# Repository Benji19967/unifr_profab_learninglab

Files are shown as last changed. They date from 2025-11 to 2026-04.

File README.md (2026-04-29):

# Prototyping and Fabrication in the Learning Lab <!-- omit in toc -->

Project for the course Prototyping and Fabrication in the Learning Lab at the University of Fribourg.

Official course repo: https://github.com/nembrinj/protofablab/tree/main

<p float="left" align="left">
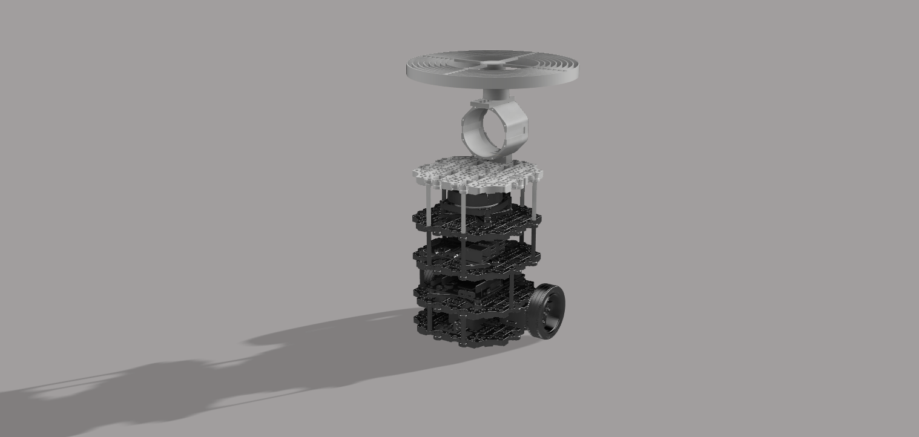
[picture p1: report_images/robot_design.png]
  
</p>

# Table of contents <!-- omit in toc -->
- [Abstract](#abstract)
- [Introduction](#introduction)
  - [Concept](#concept)
  - [Organisation](#organisation)
- [System Design](#system-design)
  - [System Architecture](#system-architecture)
  - [Robot Flow](#robot-flow)
  - [Interface](#interface)
- [Repository Structure](#repository-structure)
- [Hardware Designs](#hardware-designs)
  - [3D Printing](#3d-printing)
  - [Laser Cutting Machine](#laser-cutting-machine)
- [Process](#process)
- [Challenges](#challenges)
- [Future Work](#future-work)
- [Conclusions](#conclusions)

# Abstract

This project presents the design and implementation of a robotic scenographic system developed for a theatrical performance set on a train journey. Using a TurtleBot Burger, programmable lighting, and digitally fabricated components, the system projects dynamic shadows to simulate the perception of movement on stage. The project combines autonomous robot navigation, interactive control interfaces, and custom mechanical structures created through 3D printing and laser cutting. The result is a flexible and controllable scenic element that enhances the visual narrative of the performance through light and motion.

# Introduction

The objective of the project was to contribute to a stage performance through a technological element that enhances the visual narrative without interfering with the physical constraints of the play.

The theatrical piece is set during a train journey and is performed by a single actress who remains physically fixed to the stage, moving only from the ankles upwards. This limitation motivated the search for an alternative way to convey motion and spatial progression. To address this challenge, a TurtleBot Burger was adapted and extended with custom hardware to generate dynamic light and shadow effects on stage, simulating the changing landscape seen from a train window.

The project combines autonomous robot navigation, interactive control systems, and custom-designed mechanical components produced using 3D printing and laser cutting. Together, these elements form a flexible scenographic system capable of adapting to different moments of the performance and reinforcing the theatrical atmosphere through light, motion, and shadows.

## Concept

The core concept of the project is the use of moving shadows to suggest the sensation of travel and continuous motion within a static stage environment. By projecting silhouettes of external elements such as buildings, trees, or light poles, the system recreates the visual experience of observing the outside world through a train window.

This effect is achieved by mounting a programmable light source and a rotating structure with interchangeable silhouettes on top of a mobile robot. As the circular structure rotates, the projected shadows move across the stage, creating the illusion of a passing landscape. The distance between the light source and the silhouettes can be modified, allowing different shadow scales and visual depths.

This approach was particularly well suited to the play, as it adds dynamism to the scene without requiring additional actors or complex stage mechanisms. The robotic system remains in the background while its visual impact supports the narrative, reinforcing the idea of movement and transition that is central to the story.

## Organisation

The project was carried out by a team of two students. Due to living far from each other, in-person meetings outside scheduled class time were limited. As a result, a structured and continuous communication workflow was established.

Each week, during the class session, both team members shared and discussed the progress made individually throughout the previous week. After reviewing the current state of the project, development continued collaboratively during the class. At the end of each session, specific tasks were assigned to be completed before the following week.

In addition, any complications, technical issues, or new ideas that arose during the week were communicated via phone. When physical presence was required, such as for hardware assembly or testing, meetings were arranged before class sessions to work together on-site. This organization allowed the project to progress efficiently despite the physical distance between team members.

# System Design

Communication between electronic parts was handled wirelessly using the Robot Operating System (ROS).

The light has an integrated Arduino. The stepper motor was connected through a driver to another Arduino. Both Arduinos could be configured to connect to WiFi. On both of them a ROS package was installed, which allowed serialized communication with ROS Core running on a laptop. The light is configurable in two ways: the intensity can be adjusted, and it can be made to blink at different frequencies. For the motor, the speed and direction of rotation is configurable. 

Sending commands to the light and motor can be done via ROS commands through the CLI, or via Python code, or via a Node-RED interface. The team members ended up using the Node-RED interface as it is most flexible and easy to set up. The auto-generated Node-RED config for the final interface can be found [here](node-red/interface.json).

The code for the light Arduino can be found [here](arduino/light_ros/light_ros.ino) and the code for the motor Arduino [here](arduino/motor_ros/motor_ros.ino).

An attempt was made to make the robot fully autonomous via Python code. The code is not fully tested / functional, but can be found [here](src/turtlebot3_profab/scripts/controller.py). The launch script for the controller can be found [here](src/turtlebot3_profab/launch/controller.launch).

Mapping the environment and localizing the robot still need to be done manually. Instructions for how to do so and for many other commands can be found in the [docs](docs/instructions.md). The [makefile](makefile) provides shortcuts for many commonly used commands. 

## System Architecture

The intelligence and control center of the robot is located on the laptop. There are several ROS nodes running on the laptop:

- ROS core — in charge of coordination between all the nodes. 
- ROS serial nodes - to allow serial communication between the Arduinos and the ROS language.
- ROS server - is a bridge to allow communication between ROS core and Node-RED
- ROS navigation - in charge of coordinating robot navigation and going to goal poses using a predefined map. 

During the mapping and localization phase of the robot the following other nodes are also used:

- ROS slam - to use the lidar and create a map of the environment
- ROS teleop - to allow remote control of the robot using keyboard keys
- ROS gazebo - to run the robot in a simulation environment

The robot has a core ROS node that enables its basic functionalty and optionally a controller that allows it to navigate autonomously. 

There are ROS topics for goal navigation, motor speed control, as well as light intensity and blinking control. 

<p align="center">
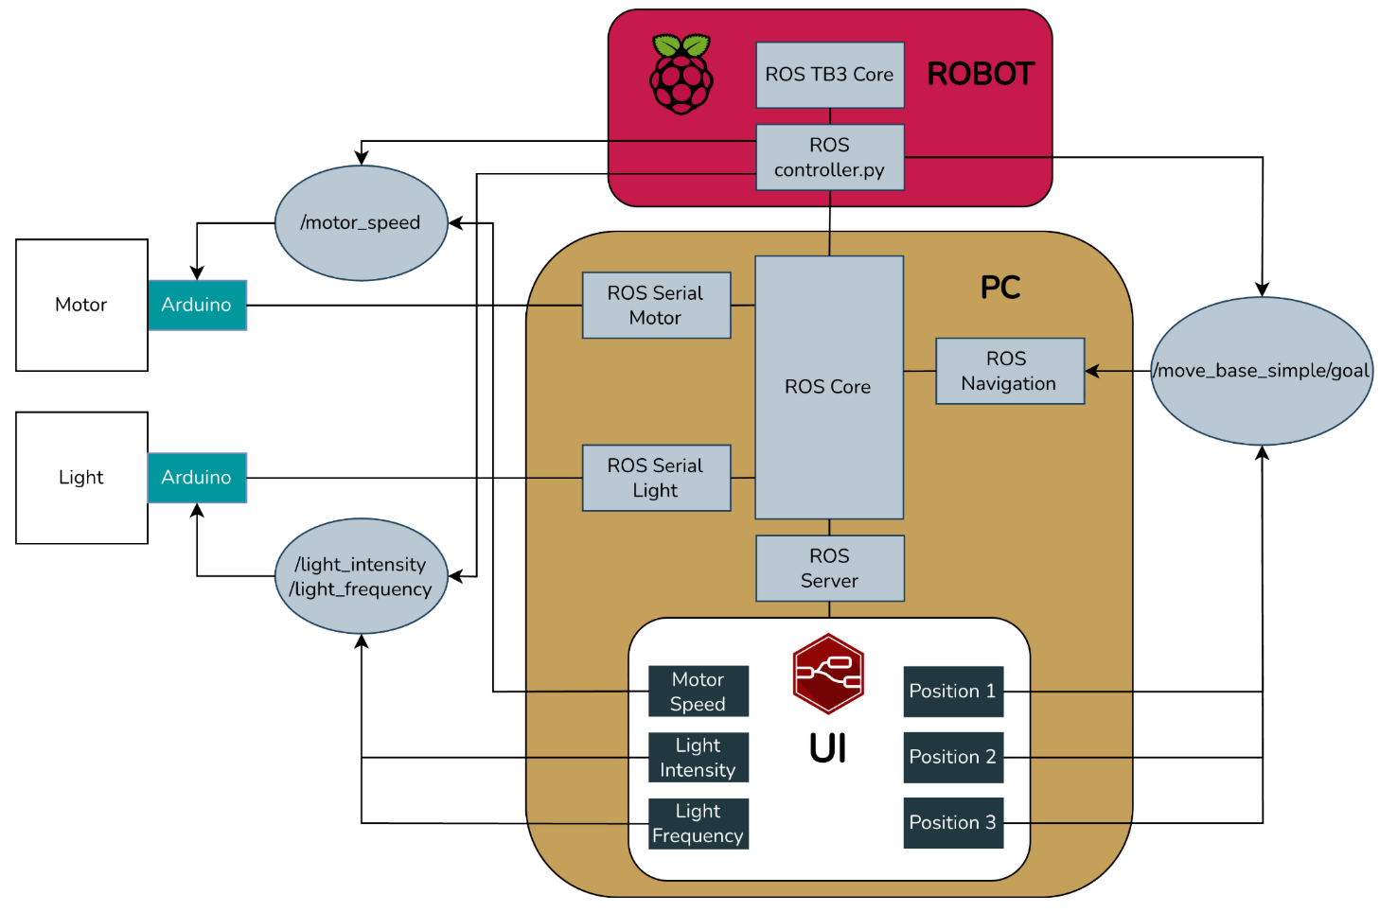
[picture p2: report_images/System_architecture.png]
System Architecture schema
  
</p>

## Robot Flow

The flow of the robot for the project is as follows. First the environment is mapped and saved manually. Then, using the RVIZ interface the coordinates of three goal poses are obtained, which are inserted into the Node-RED UI. Then the robot is launched and one of the goal poses is chosen in the UI. In response, the robot will move to the defined pose. Once there, the light and motor are manually turned on which starts the projection of the shadow scene onto the background. The light intensity, blinking frequency, and motor rotation speed can all be adjusted. Once the play is over, the robot goes back behind the scene.

<p align="center">
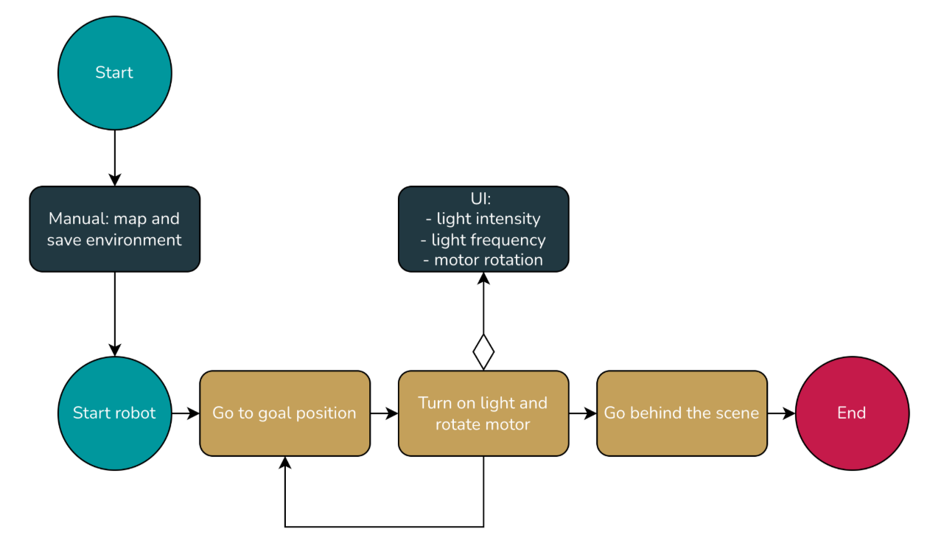
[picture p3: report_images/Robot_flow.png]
Robot flow schema
  
</p>

## Interface

Light, motor and robot position control all happen through a Node-RED interface that talks to the respective components via ROS topics. The three positions define goal poses and, when clicked, send the robot in front of one of the scenes to project the shadow. 

<p align="center">
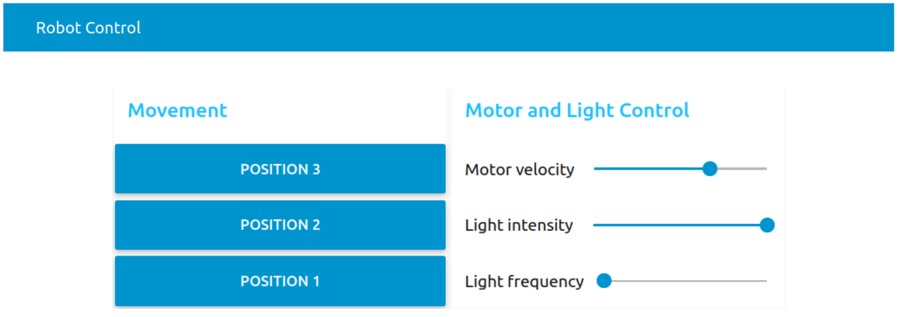
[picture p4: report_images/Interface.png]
Interface
  
</p>

# Repository Structure

    .
    │
    ├── 3d_models                           # 3D models of pieces to print —- .mf and .bgcode files
    │
    ├── arduino                             # Arduino code to control the light and motor
    │
    ├── docs                    
    │   ├── hardware.md                     # Hardware used for the project
    │   └── instructions.md                 # How-tos: Raspberry Pi, Arduinos, Node-RED, Turtlebot, ROS
    │
    ├── map                                 # Maps of the environment created using ROS Navigation
    │   
    ├── node-red                            # Node-RED dashboard files
    │   
    ├── report_images                       # Assets used in the report
    │   
    ├── requirements                        # Dependencies needed to set up the robot and the workstation
    │
    ├── src / turtlebot3_profab / launch    # Launch scripts
    │
    ├── src / turtlebot3_profab / scripts   # Python scripts to control the robot
    │
    ├── makefile                            # Shortcuts for ROS commands 
    │
    └── README.md

# Hardware Designs

Several custom components were required to support the lighting system, the rotating shadow mechanism, and the additional electronics while maintaining stability and modularity.
Digital fabrication tools played a key role in this process. 3D printing was used to create structural and mechanical supports, while the laser cutting machine was employed to produce the shadow silhouettes and flat components. These techniques allowed for rapid iteration, precise customization, and easy adaptation of the system to the requirements of the performance.

## 3D Printing

3D printing was used to fabricate all custom structural components required to extend the TurtleBot Burger and integrate the lighting and shadow projection system. These parts were designed to be modular, lightweight, and easy to assemble, allowing the system to be mounted securely on top of the robot without interfering with its original structure or sensors.

The printed components include an additional base, support structures for the programmable light, and a vertical mount to hold the stepper motor responsible for rotating the shadow element. The light support was designed with multiple mounting positions on the base, enabling adjustments to its height and placement. Similarly, the motor could be mounted in different positions on the light support, providing flexibility in the overall configuration.
The rotating piece placed above the motor was also designed with several concentric positions to attach silhouette elements. This modular arrangement makes it possible to vary the distance between the light source and the silhouettes, which is a key aspect of the system. Adjusting this distance significantly affects the resulting shadows, influencing their size, sharpness, and overall visual appearance. This flexibility allows the system to adapt to different silhouettes and stage scenarios, producing distinct visual effects depending on the desired atmosphere.

In the image of the left, the custom 3D-printed components can be seen assembled on the TurtleBot Burger. The printed parts are shown in white, clearly distinguishable from the original robot components, which are black. This contrast highlights the added structures and their integration with the existing platform.

The right image shows only the 3D-printed parts prior to assembly. This view emphasizes the modular nature of the design and the variety of supports created to accommodate the different hardware elements. The use of 3D printing allowed rapid prototyping and iterative refinement of these components throughout the development process.

<p float="left" align="center">
  
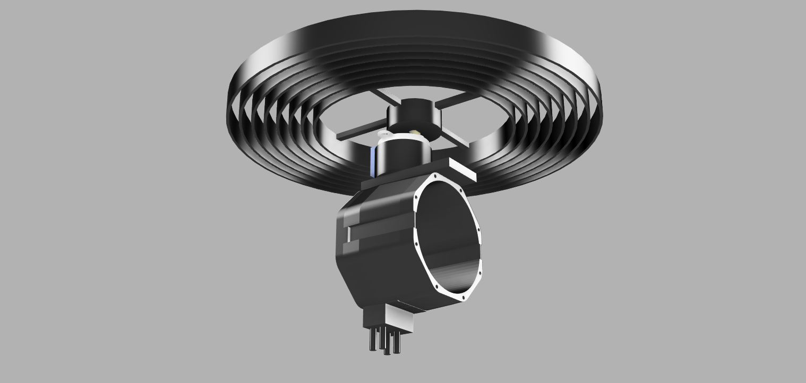
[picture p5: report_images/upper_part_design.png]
  
</p>

## Laser Cutting Machine

The laser cutting machine was used to fabricate the silhouette elements responsible for generating the projected shadows. For this purpose, it was necessary to select a material that was lightweight and easy to cut, while also being more resistant and stable than standard paper. A paper with higher grammage than a regular sheet was chosen, as it provided the required balance between rigidity, durability, and low weight.

The silhouettes were designed digitally and then cut using the laser cutting machine. This approach was significantly more efficient and less costly in terms of time and effort than manual cutting. Once the designs were prepared, the fabrication process was straightforward and easily repeatable.

One of the main reasons for using laser cutting was the high level of precision and the clean edges it provides. This aspect was especially important for the project, as small imperfections in the silhouettes become highly noticeable when projected as shadows. Clean and accurate cuts resulted in sharper, more defined shadows, directly improving the visual quality of the final scenographic effect.

<p align="center">
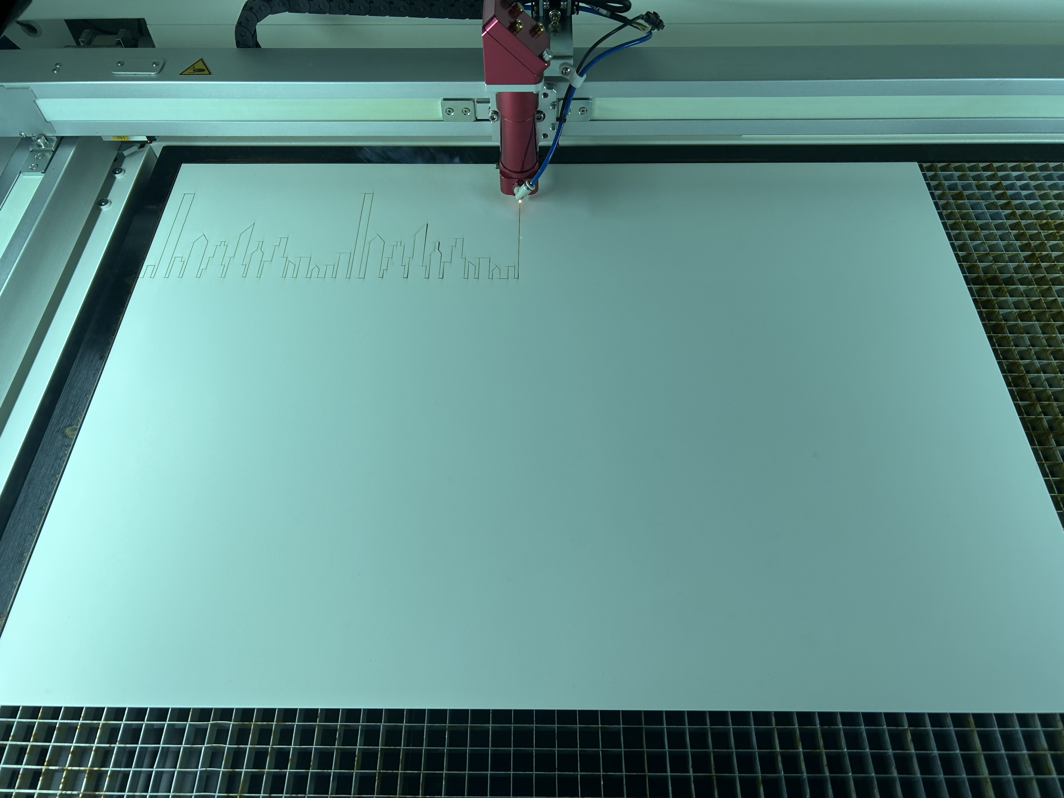
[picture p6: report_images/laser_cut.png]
Laser cut
  
</p>

# Process

The development of the project followed an iterative process that combined research, hardware fabrication, and software implementation.

The first step consisted of evaluating the feasibility of the initial idea. This phase focused mainly on researching the type of motor required for the rotating shadow mechanism. It was determined that a stepper motor was more suitable than a servo motor due to the need for continuous and controllable rotation. In parallel, different lighting solutions were explored in order to generate clear and defined shadows. This issue was later solved when suitable programmable lights were provided. Additionally, initial tests with 3D printing were carried out, revealing that printing components was time-consuming and required careful planning to avoid delays.

After this initial research phase, a basic planning stage was carried out to ensure that all project deadlines could be met while accounting for possible setbacks. The fabrication of 3D-printed components was prioritized, as multiple iterations were expected due to potential design errors or failed prints. Furthermore, several of these components were essential to begin testing the robot in real conditions.

The first parts to be designed and printed were the additional base for the robot and the initial support structures. While these components were being printed, work began on the implementation of the robot’s navigation and mapping system, allowing progress on both hardware and software in parallel.

At a later stage, once the stepper motor and the lighting system were available, the design and printing of the light support, the motor mount, and the rotating piece for holding the silhouettes were carried out. During this period, the control code for the stepper motor and the programmable light was developed and tested independently.

<p align="center">
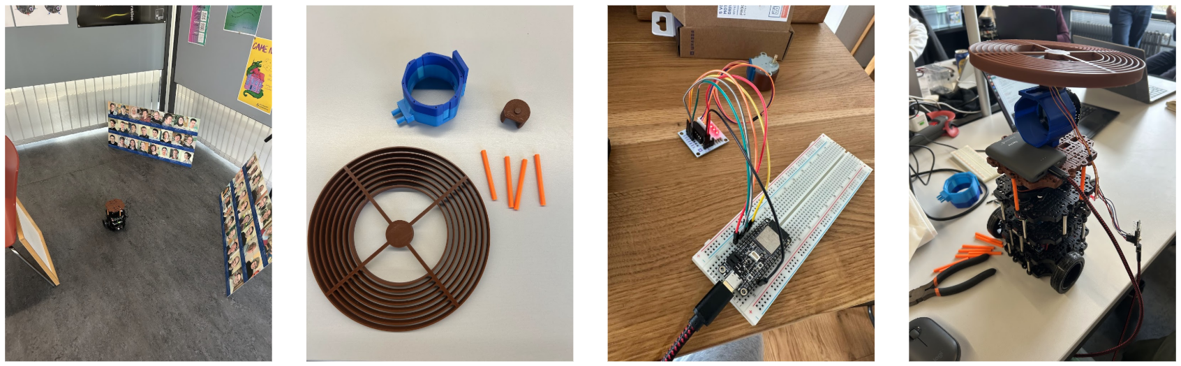
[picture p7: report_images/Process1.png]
First images of the process
  
</p>

With these components printed and assembled, the system was tested as a whole, which led to the identification of several issues. The main problem was that the initial rotating piece was too small, causing the silhouettes to be positioned too close to the light source and resulting in poor shadow quality. To address this issue, a new and larger rotating piece was designed and printed. At the same time, development of the user interface continued, and the overall software was automated to allow the entire system to be executed easily, enabling any user to control the robot through the interface without technical knowledge.

<p align="center">
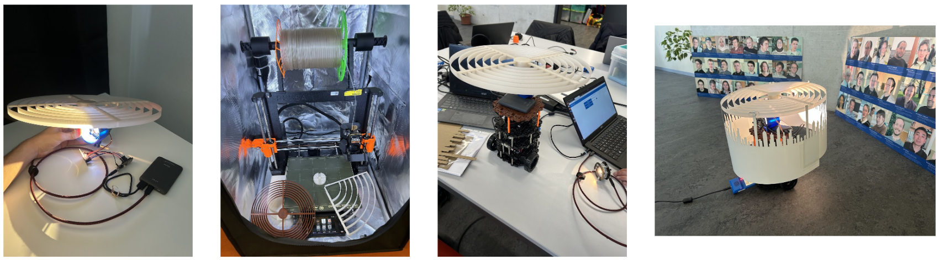
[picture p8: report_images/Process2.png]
Last images of the process
  
</p>

Finally, once all components were correctly fabricated, assembled, and integrated, the last phase focused on fine-tuning the system. Multiple simulations and tests were performed to determine the most effective configurations for rotation speed, light intensity, and distance between the light source and the silhouettes, ensuring the best visual results for the stage performance.

<p align="center">
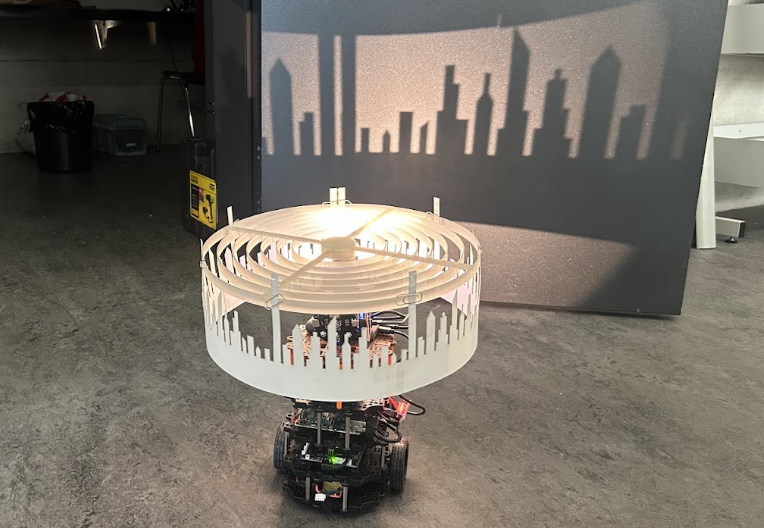
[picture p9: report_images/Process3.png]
Final version
  
</p>

# Challenges

One of the first challenges was the selection of the appropriate motor for the rotating shadow mechanism. The system required a motor capable of rotating continuously in both directions without limitation. A servo motor was not suitable for this purpose, as it can only rotate within a fixed angular range. After researching different options, a stepper motor was selected, as it allows precise and unlimited rotation control. However, finding a stepper motor compatible with Arduino and with low power requirements introduced additional constraints. To meet these requirements, the use of a motor driver was necessary, adding complexity to both the hardware setup and the software control.

Another major challenge was achieving the correct alignment between the light source and the silhouettes to obtain high-quality shadow projections. Depending on the type of silhouettes used and the specific stage configuration, the required distances and sizes varied significantly. Finding an optimal configuration through trial and error would have been inefficient and costly. To address this, several adjustable components were incorporated into the robot design. The light support could be mounted in different positions on the base, allowing the light to be placed either at the center or offset from it. The motor could also be positioned at varying distances relative to the light source, depending on whether the rotating element needed to align centrally or not. Finally, the rotating piece itself featured multiple concentric positions for attaching silhouettes, enabling fine control over the distance between the light and the silhouettes. Although this approach increased the complexity of the mechanical design, it significantly reduced printing time and material waste while providing great flexibility and precise shadow control.

The fabrication of the rotating piece presented an additional challenge. The initial design was too small, resulting in silhouettes being placed too close to the light source and producing poor shadow quality. When redesigning the piece at a larger scale, the 3D printer was unable to print it as a single component due to size limitations. To overcome this, the rotating piece was redesigned as a modular structure composed of six interlocking parts. This solution ensured sufficient size while maintaining structural robustness and low weight. Careful attention was given to weight distribution, as uneven mass or imprecise assembly could cause imbalance during rotation, negatively affecting the shadow effect. The modular design allowed precise assembly without excessive use of adhesive, minimizing the risk of imbalance.

Finally, several challenges were encountered during software execution and system integration. At times, the robot failed to connect correctly, localization was inaccurate, or the motor and light systems stopped responding. Through iterative debugging, it became clear that the order in which different components and processes were executed was critical. Additionally, maintaining a consistent stage setup after the environment had been mapped proved essential, as any change affected localization accuracy. Ensuring stable power connections, particularly avoiding disconnections of the motor or light once integrated with the ROS system, was also identified as a key factor for reliable operation.

# Future Work

One potential improvement is the ability to project multiple static scenes without the need to change silhouettes manually and without relying on continuous motion. This could be achieved by designing a single rotating disc containing several static scenes distributed along its diameter. In this configuration, the robot would move to a specific position on the stage and project a selected scene. When a scene change is required, the rotating piece would rotate by a small, controlled angle to align a different scene with the light source. This approach would allow multiple scenes to be stored on the robot and displayed sequentially through minimal rotation.

Another possible extension is the creation of two concurrent scenes with a parallax effect. In this scenario, two different silhouette layers would rotate in opposite directions, generating a greater sense of depth and visual complexity. Achieving this effect would require the integration of an additional motor and a modification of the robot’s mechanical structure to allow both rotating elements to move independently while keeping the light source fixed. This enhancement could significantly enrich the visual language of the system and open new creative possibilities for stage design.

# Conclusions

This project demonstrates how robotics and digital fabrication can be effectively applied to a theatrical and scenographic context. By combining autonomous robot navigation, programmable lighting, and custom-fabricated mechanical components, it was possible to create a dynamic visual system that enhances the narrative of the performance without adding physical actors or complex stage machinery.

The use of shadows as a primary visual element proved to be a suitable solution for conveying movement in a constrained stage environment. The modular and adjustable design of the hardware allowed the system to adapt to different silhouettes, lighting conditions, and stage configurations, highlighting the importance of flexibility in prototyping for artistic applications.

Throughout the development process, the project emphasized iterative design, problem-solving, and the integration of hardware and software. Challenges related to motor selection, fabrication constraints, and system reliability provided valuable insights into the practical limitations and considerations of working with robotic platforms in real-world scenarios.

Overall, the project successfully met its objectives and illustrates the potential of repurposing robotic systems as expressive tools in performance and learning environments. The resulting system offers a solid foundation for future extensions and further exploration of robotics as a medium for artistic expression.

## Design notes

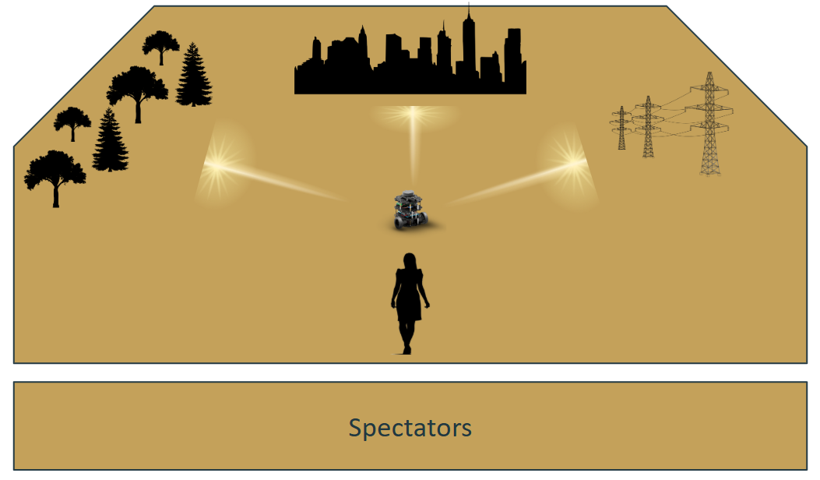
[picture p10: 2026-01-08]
report_images/Stage.png

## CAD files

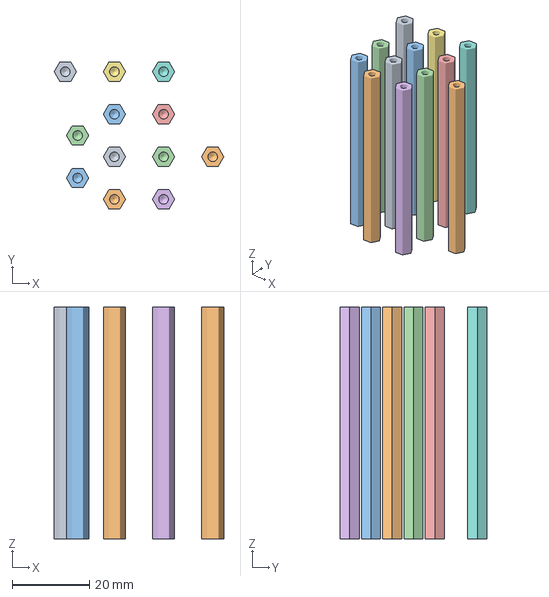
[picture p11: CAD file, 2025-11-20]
3d_models/SUPPORT_HEX_M3_0XL60_FF_multiple.3mf
43.9 x 38.0 x 60.0 mm

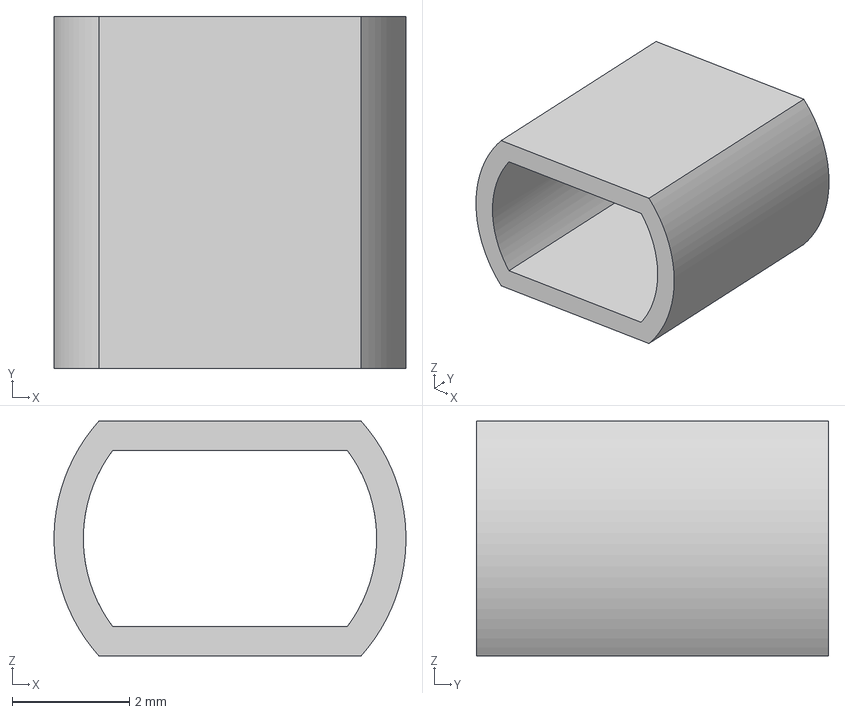
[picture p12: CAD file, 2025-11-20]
3d_models/motor_adapter_1.3mf
6.00 x 6.00 x 4.00 mm

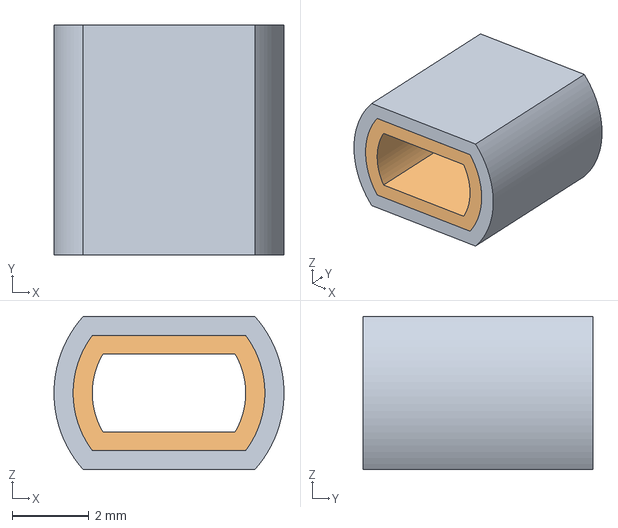
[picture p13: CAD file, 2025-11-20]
3d_models/motor_adapter_2.3mf
6.00 x 6.00 x 4.00 mm

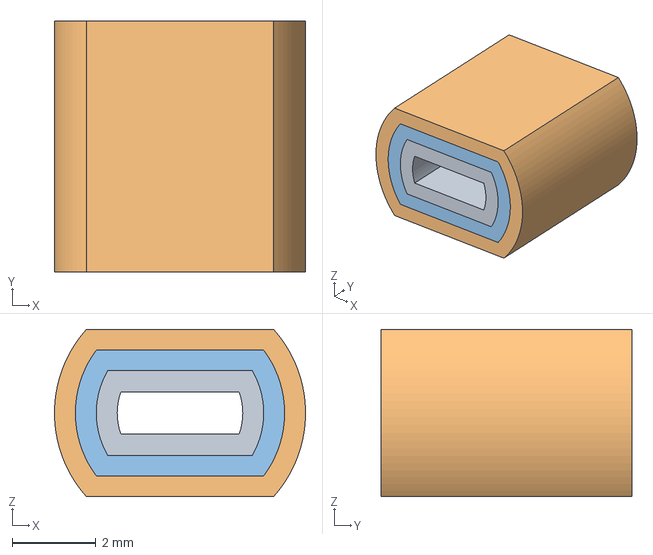
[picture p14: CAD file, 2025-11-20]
3d_models/motor_adapter_3.3mf
6.00 x 6.00 x 4.00 mm

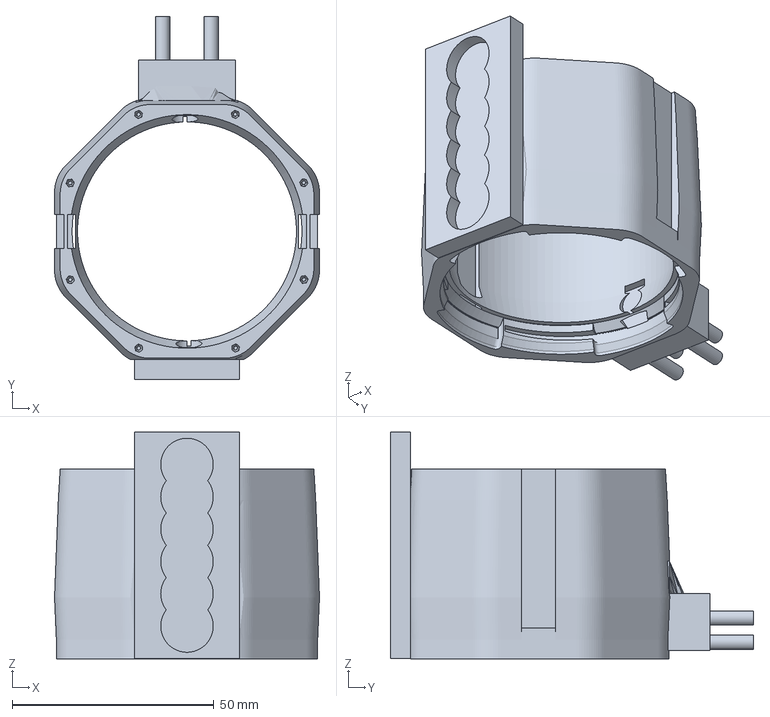
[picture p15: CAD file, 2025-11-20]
3d_models/light_tube.3mf
65.6 x 90.0 x 56.1 mm

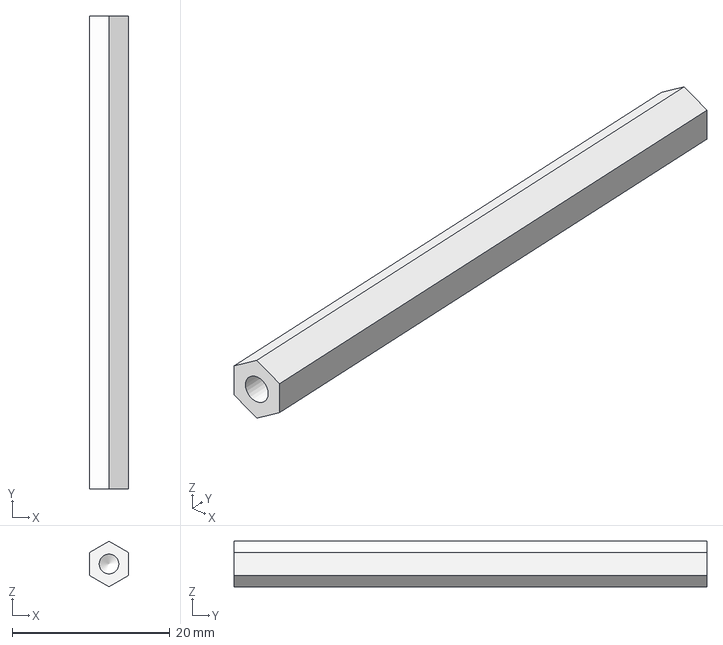
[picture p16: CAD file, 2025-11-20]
3d_models/SUPPORT_HEX_M3_0XL60_FF.3mf
5.00 x 60.0 x 5.77 mm

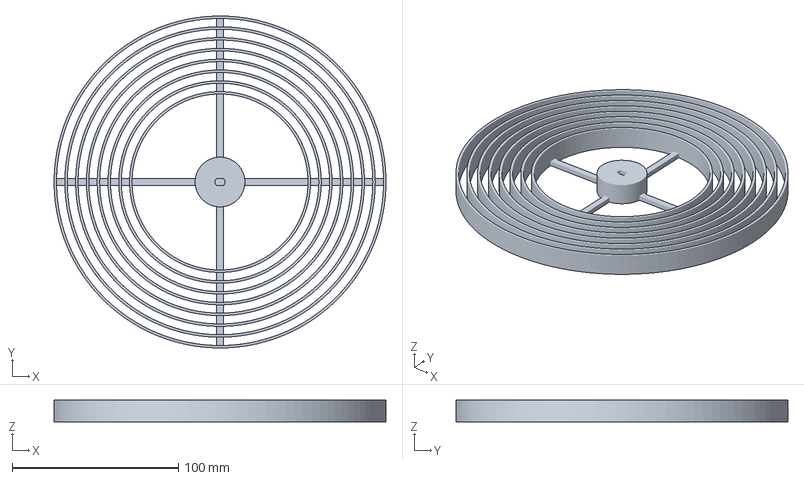
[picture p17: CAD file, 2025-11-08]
3d_models/rotating_piece _v2.3mf
200.0 x 200.0 x 13.0 mm

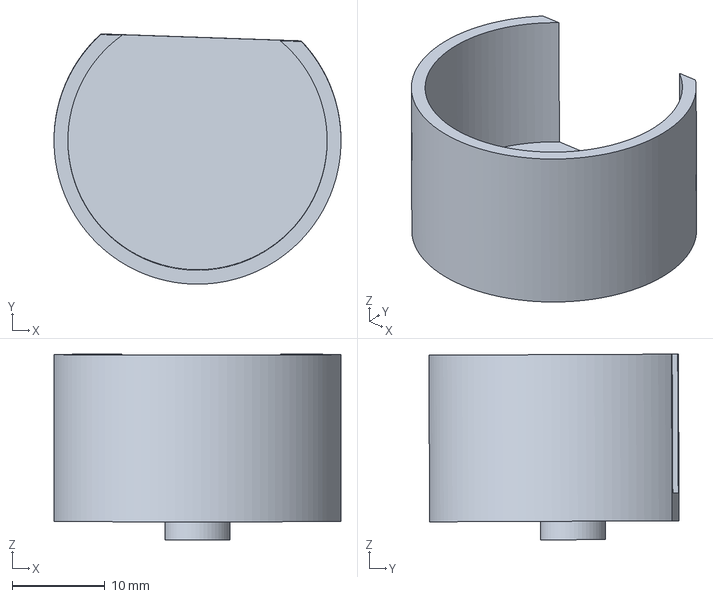
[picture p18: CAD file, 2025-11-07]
3d_models/motor_base.3mf
31.0 x 27.0 x 20.1 mm

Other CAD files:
3d_models/light_tube.f3d
3d_models/motor_base.f3d
3d_models/rotating_piece _v2.f3d

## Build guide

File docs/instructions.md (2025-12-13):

## Creating a package

```bash
cd src/
catkin_create_pkg turtlebot3_profab std_msgs turtlebot3_msgs sensor_msgs geometry_msgs rospy
```

## Installing external packages

### On the robot

Repo dependencies
```shell
sudo apt-get install python3-vcstool
cd src/
vcs-import < ../dependencies-bot.repos
```
Binary dependencies
```shell
./install_apt_requirements.sh requirements/robot-requirements.apt
```

## Finding the IP address of the Raspberry Pi

Make sure the Raspberry is connected to the same local network as 
your laptop/PC (e.g. use ethernet cable for the Raspberry Pi)

```shell
hostname -I
sudo nmap -sn <hostname>/24
```
find ubuntu entry

## Updating the Wifi settings on the Raspberry Pi

```shell
sudo vim /etc/netplan/50-cloud-init.yaml
```

## Git user isolation on bot (not great, separate HOMEs)

```shell
sudo adduser <name>
git config --global user.name "<name>"
git config --global user.email "<email>"
```

## Using ssh key of laptop

```shell
ssh -A <user>@<ip>
```

## Launch Node-RED dashboard

```shell
node-red node-red/<dashboard name>
```

## Controlling the (Arduino) light intensity via a ROS Node

Deploy `./arduino/light_ros` onto the arduino (use correct Wifi credentials). 

Make sure tcp port (`make light_node`) and topic name match up with the Arduino code. 

Make sure the IP Adress in the Arduino code matches the roscore ip adress

In 2 different terminals:

```shell
roscore
make light_node
```

In a third terminal:

```shell
rostopic pub light_intensity std_msgs/Int16 <value between 0 and 255> --once
```

## Controlling the (Arduino) light intensity via Node-RED

```shell
make server
make light_node
node-red ./node-red/light_ros.json
```

## Controlling the motor speed (in RPMs) via a ROS Node
Deploy `./arduino/motor_ros` onto the arduino (use correct Wifi credentials). 

Make sure tcp port (`make motor_node`) and topic name match up with the Arduino code. 

In 2 different terminals:

```shell
roscore
make motor_node
```

In a third terminal:

```shell
rostopic pub motor_speed std_msgs/Int16 <value between 0 and 15> --once
```

or, for negative values:

```shell
rostopic pub motor_speed std_msgs/Int16 "data: <value between -15 and 15>" --once
```

## Creating a custom map

```shell
make robot (on robot)
roscore
make gazebo
make slam
make teleop 
```

move around using teleop.

Saving the map:
```shell
rosrun map_server map_saver -f ~/profab_ws/map/<map_name>
```

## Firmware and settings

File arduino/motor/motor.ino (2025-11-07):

// This Arduino example demonstrates bidirectional operation of a
// 28BYJ-48, using a WPI401 - ULN2003 interface board to drive the stepper.
// The 28BYJ-48 motor is a 4-phase, 8-beat motor, geared down by
// a factor of 68. One bipolar winding is on motor pins 1 & 3 and
// the other on motor pins 2 & 4. The step angle is 5.625/64 and the
// operating Frequency is 100pps. Current draw is 92mA.

////////////////////////////////////////////////
//declare variables for the motor pins
int motorPin1 = 9; 
int motorPin2 = 10; 
int motorPin3 = 11;
int motorPin4 = 12;
// Red - 28BYJ48 pin 5 (VCC)
int motorSpeed = 1200; //variable to set stepper speed
int numSteps = 0;
int stepsPerRevolution = 512; // number of steps per full revolution
int lookup[8] = {B01000, B01100, B00100, B00110, B00010, B00011, B00001, B01001};
//////////////////////////////////////////////////////////////////////////////
void setup() {
  //declare the motor pins as outputs
  pinMode(motorPin1, OUTPUT);
  pinMode(motorPin2, OUTPUT);
  pinMode(motorPin3, OUTPUT);
  pinMode(motorPin4, OUTPUT);
  Serial.begin(9600);
}

//////////////////////////////////////////////////////////////////////////////
void loop(){
  if(numSteps < stepsPerRevolution)
    clockwise();
  else
    anticlockwise();
  if (numSteps == stepsPerRevolution * 2)
    numSteps = 0;
  numSteps++;
}
//////////////////////////////////////////////////////////////////////////////
//set pins to ULN2003 high in sequence from 1 to 4
//delay "motorSpeed" between each pin setting (to determine speed)
void anticlockwise()
  {
    for(int i = 0; i < 8; i++)
    {
      setOutput(i);
      delayMicroseconds(motorSpeed);
    }
}
void clockwise()
{
  for(int i = 7; i >= 0; i--)
  {
    setOutput(i);
    delayMicroseconds(motorSpeed);
  }
}
void setOutput(int out)
{
  digitalWrite(motorPin1, bitRead(lookup[out], 0));
  digitalWrite(motorPin2, bitRead(lookup[out], 1));
  digitalWrite(motorPin3, bitRead(lookup[out], 2));
  digitalWrite(motorPin4, bitRead(lookup[out], 3));
}

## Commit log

2025-10-03 Make robot switch goal if within 50cm of goal
2025-10-24 Add finding the ip of the raspberry pi
2025-10-25 Add driver dependency
2025-10-25 Add requirements for camera
2025-10-25 Add launch files for camera
2025-10-25 Add arduino code for light with potentiometer
2025-10-26 feat: add node-red ros flow to control robot
2025-10-26 feat: add battery state to node-red dashboard
2025-10-26 feat: add basic server to control light arduino
2025-10-31 Add waffle plate to use as another layer for the bot
2025-11-01 docs: update camera instructions
2025-11-03 First version fo the rotating piece #9
    [rotating_piece.stl]
2025-11-06 Motor base and rotating piece designs
    [motor_base.3mf, motor_base.f3d, rotating_piece.3mf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]
2025-11-07 feat: add basic motor arduino code
2025-11-07 feat: add simpler motor control code using library
2025-11-07 feat: add controlling the motor speed via a ROS node
2025-11-09 feat: add option to use camera plugged in to laptop
2025-11-14 feat: add 3D support rods for turtlebot
    [SUPPORT_HEX_M3_0XL60_FF.3mf]
2025-12-04 Update values motor speed: -15 to 15
2025-12-04 feat: control motor and light via node red interface
2026-01-15 chore: update report -- robot flow and interface
